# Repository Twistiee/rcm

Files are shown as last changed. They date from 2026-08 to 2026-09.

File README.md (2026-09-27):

# RCM — Relay Control Module

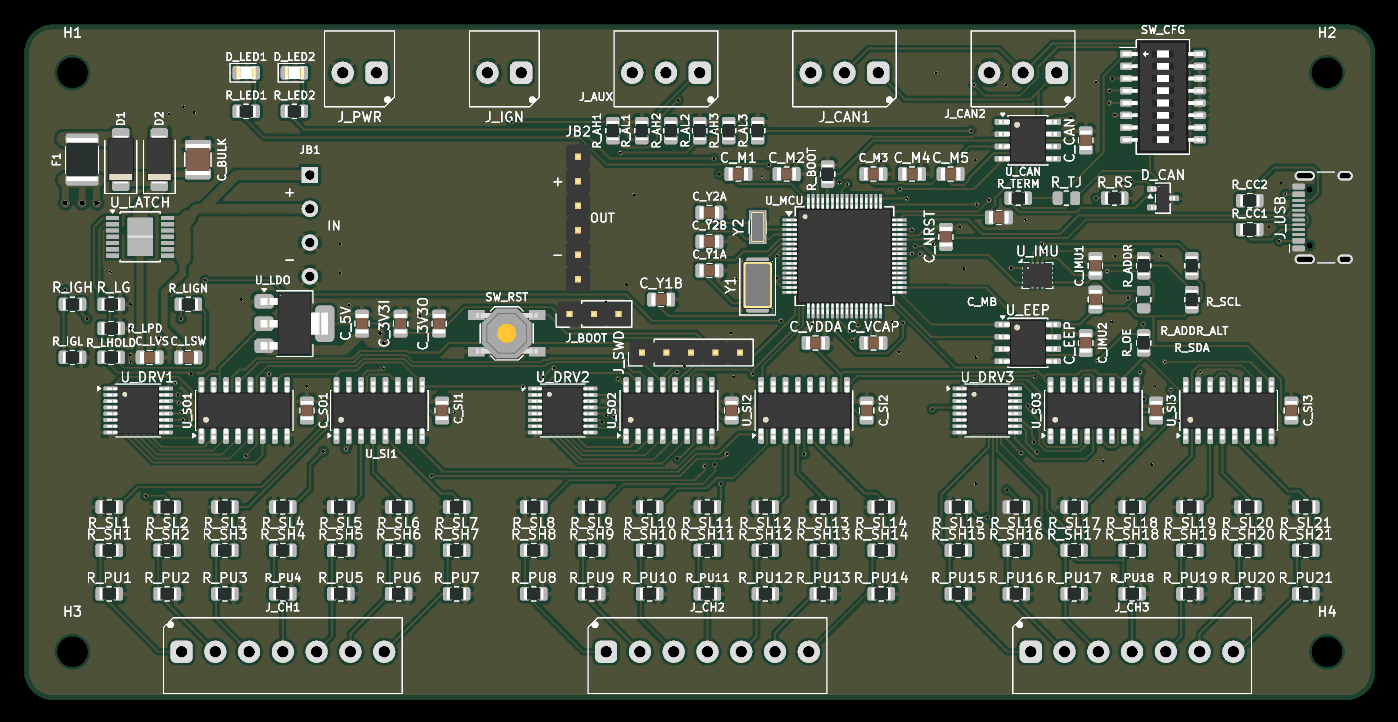
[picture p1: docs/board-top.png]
RCM board, top view


A CAN-controlled relay driver for a car. **21 universal channels**, each of which is
simultaneously a low-side output *and* an input — so the same board builds as a relay
controller or as a switch panel, decided in firmware rather than by a different PCB.

Designed for a [rusEFI](https://rusefi.com/) bus (uaEFI SUPER ECU + uaDASH display), but
nothing about it is rusEFI-specific beyond the choice of message IDs.

> ### A note on how this was built
>
> **This project is largely AI-developed.** The schematic, PCB layout, firmware and
> documentation were written by me working with Claude, and much of the text and code here
> came out of that. It is called out up front because some people would rather know, and
> because it should colour how much you trust it.
>
> What it does *not* mean is unreviewed or untested. The board exists and has been brought
> up on the bench; the claims in the Status section below were measured rather than
> asserted, and where something has only been reasoned about it says so. The firmware has a
> host-side unit test suite. Bring-up still found real bugs that review had missed — which
> is rather the point of the Status section.
>
> Treat it as you would any one-person hobby project: read the schematic before you build
> it, and don't put it in charge of anything you can't afford to have fail.

---

## Status — read this first

**revA has been built, powered and brought up.** Every subsystem has run on real
hardware: the MCU and its 8 MHz crystal, USB, the DIP straps, the EEPROM, CAN through the
transceiver onto a real bus, the IMU, the 12 V sense, the self-latching power, the
watchdog, the output drivers under a real relay load, a stored configuration surviving a
full save-reset-read cycle, and the board switching itself off. 268 host unit tests pass
alongside that.

What that does **not** mean is that it is proven in a car. Specifically, still untested:

- **board-to-board peer mirroring** — the keypad role strap is proven and a board does
  come up as a keypad, but only one board has ever been powered, so the peer link has been
  exercised only with a PC pretending to be the other board
- **more than two channels under load at once**, and nothing thermal

One genuine hardware flaw has been found, and it is a missing capability rather than a
functional fault: **revA cannot reach USB DFU.** `BOOT1` is `PB2`, which this board uses
for `SR_OE_N` and holds high at reset, so lifting BOOT0 boots from SRAM instead of the ROM
bootloader. The `J_BOOT` header is fitted and works; the pin conflict defeats it. Firmware
therefore needs an ST-Link on `J_SWD`. Configuration is unaffected — that is all over CAN.
`DESIGN.md` has the analysis and the one-net revB fix.

Bring-up found three real firmware bugs that no amount of desk testing had: a `%f` in
printf corrupting memory, a strap display that could never show a change, and a short
press on the ignition button switching the board back off. `DESIGN.md` records those and
everything else found along the way, which is a fair guide to how much is probably left.

### What happens when it resets

This is a PDM. Running a main relay, a fuel pump and an injector feed is the job, not an
edge case. But there is one behaviour to design around:

**On any reset, `R_OE` parks all 21 channels high-impedance until firmware re-enables
them.** Every channel drops. The firmware adopts `failsafe_state` and goes live as its
first act, and on revA hardware that is **22 ms**, measured by the self-test build's `W`
command rather than estimated. Add a few ms of pre-`main()` crystal and PLL startup that
`millis()` cannot see, so call it **~25 ms**. That applies equally to a cold start and to
a watchdog reset, so a main relay behind this board closes with the key rather than after
a timeout.

Most of the 22 ms is the EEPROM: the board cannot apply `failsafe_state` before it has
read `failsafe_state`, so `cfg_load()` is unavoidably inside the dropout. A scope on any
channel gives the true figure including pre-`main()` time.

So the question for each load is not "is this engine-critical" but **"what does 25 ms off
do to it?"**

| Load | 25 ms off | Verdict |
|---|---|---|
| Fan, fuel pump, lights, horn, accessories | invisible | fine |
| Injector / coil supply via a main relay | at worst a single missed event | **fine — set `failsafe_state` to hold it on** |
| **ECU power itself** | the ECU reboots, which really is a stall | **give the ECU its own ignition-switched feed** |
| **Brake lights** | harmless in itself | **hardwire anyway** — see below |

**`failsafe_state` is the board's resting state**, not just a bus-timeout behaviour: it is
what gets applied at power-up, after a watchdog reset, and whenever the bus goes quiet —
anything a CAN command has not overridden. It defaults to all-off, which is right for
lighting and wrong for anything that should be on by default. It is per-channel, so one
board can drop its lighting and hold its engine loads. Set it deliberately.

**Brake lights are a different argument.** Not dropout time — a hardwired brake switch is
simply simpler and more reliable than anything running on a microcontroller, and there is
no upside to inserting one. Wire the switch straight through, and tap the switched feed
into a spare channel set to `CH_INPUT` if you want the board to know about it. 1.2 mA, and
it cannot affect the lamps.

Roadworthiness and legal compliance of anything you build with this are yours.

---

## What it does

| | |
|---|---|
| **Channels** | 21, low-side switched, 7 per driver |
| **Drivers** | 3 × TPL7407L (MOSFET, not Darlington — see below) |
| **I/O expansion** | 74HC595 out / 74HC165 in, daisy-chained |
| **MCU** | STM32F446RET6, LQFP-64 |
| **Bus** | CAN, switchable termination, any exact bitrate |
| **Sensing** | every channel is read back continuously, including while driving |
| **IMU** | Bosch BMI270, 6-axis |
| **Board** | 140 × 70 mm, 4-layer, solid ground plane |

## Ratings

| | |
|---|---|
| Supply | 7–30 V (12 V nominal); board draws ~100 mA |
| **Per channel, one or two on** | **600 mA** sink, 30 V max |
| **Per channel, all 7 of a tile on** | **~250 mA** — limited by the driver package, not the silicon |
| All 21 channels | ~3.5 A total with typical 85 Ω relay coils |
| Ground return | **all channels share one pole on `J_PWR`**, ~8 A |
| Ambient | −20 to +70 °C |

The channels **switch relay coils, they do not carry load current** — that is the whole
architecture. `DESIGN.md` has the worked numbers, including why 600 mA is not an all-on
figure.

## The channel trick

Each channel's terminal connects to three things at once — a driver output, a permanently
connected 1M/270k sense divider, and a fitted 10k pull-down:

- **As an output** it sinks a relay coil to ground.
- **As an input** a button wired to +12V pulls it high; the pull-down gives 1.2mA of wetting
  current, enough to keep switch contacts from going oxide-flaky.
- **As a diagnostic**, because the divider never disconnects, an idle channel reads battery
  voltage through a healthy relay coil and 0V through a blown fuse. **Fuse detection falls
  out of the same wiring** — no extra parts.

Getting all three from one resistor took a few goes. A pull-*up* would have been the obvious
choice and it silently breaks fuse sensing: blown and healthy both read high, 20mV apart.

The same pull-down has a sting worth knowing: an un-driven channel is **not open**, it is
10k to ground, and it will pass ~1mA from anything pulled up to 12V. Relay coils ignore
that. Optocouplers and MOSFET gates do not — so a generic "active low" relay module wired
straight to a channel sits with its relays energised. `DESIGN.md` has the fix.

## Configuration

An 8-way DIP sets what can't be fixed over the bus once it's wrong:

| Pos | Function |
|---|---|
| 1 | CAN termination (passive, parallels a solder jumper) |
| 2 | Role — relay module or keypad |
| 3–4 | Node address |
| 5 | CAN bitrate — forces 500k, for when you configure yourself off the bus |
| 6 | Publish IMU data — only one board per car should |

Four relay modules and four keypads can share a bus. Everything else — channel modes,
bitrate, message IDs, failsafe states — lives in EEPROM and is changeable over CAN.

## Firmware

PlatformIO + STM32duino, in [`firmware/`](firmware/) — see
[`firmware/README.md`](firmware/README.md) for the detail.

- 21 channels, in or out per channel as a **software** table, changeable over CAN
- **Coil-circuit diagnosis** — blown fuse, missing relay, open coil or broken wire, all
  reported per channel, and a short-to-12V too
- **Input behaviours**: momentary, **toggle** (a momentary button driving a latching
  load), and **hold-to-arm** (true only once held, for things a knock must not arm)
- **Output behaviours**: steady, flash on a shared period so several channels stay in
  phase, single pulse, and delay-off
- CAN at **500 kbps by default and any exact bitrate you like**. Bit timing is solved at
  runtime for an 87.5% sample point; if a rate cannot be produced exactly, it refuses to
  start rather than running the bus 1% out
- Node addressing for 8 boards, CAN-loss failsafe, ignition-off shutdown, watchdog
- **Everything is configurable over CAN, and readable back over CAN** — every setting has
  a getter as well as a setter, so a tool can ask a board what it is rather than infer it
- Optional **keypad → relay peer mirroring**, so a button panel can drive a relay module
  with no ECU in the middle

```
pio run -d firmware                     build
pio run -d firmware -e selftest -t upload   bring-up console over USB-C
pio test -d firmware -e native          268 host unit tests
```

**Two bring-up paths.** A **USB-C console** needs nothing but the cable — it proves the
DIP, the EEPROM, the CAN controller via internal loopback, the IMU, and walks all 21
channels. A **PC-side CAN tool** (`firmware/tools/rcm_bench.py`, any python-can interface)
does monitoring, commanding and the same channel walk over the bus.

The unit tests compile the firmware's own source against a model of the board — the shift
register chains bit by bit, each channel's electrical behaviour, and the EEPROM including
its page-wrap misbehaviour. They exist because the shift-register byte order is the one
thing in this design that cannot be checked by reading the code back.

### rusEFI

Message IDs were checked against rusEFI's own source rather than guessed. The board sits at
base `0x300`, clear of everything rusEFI uses (`0x100`/`0x102`, `0x130`/`0x131`, `0x190`,
`0x200`–`0x20B`, OpenBLT, OBD2). The base is configurable if it clashes with something on
your loom.

[`docs/rcm.dbc`](docs/rcm.dbc) is generated from the firmware headers, so **uaDASH and
TunerStudio can render channel state, inputs and faults with no custom display code**.

**The board can drive channels from the ECU's own decisions, and ask the ECU to act.**
rusEFI broadcasts what it thinks its relays should be doing — main relay, fuel pump, both
fans, O2 heater, check-engine, rev limiter — as single bits. Any of those can be bound to
a channel, so the ECU decides and this board switches, which matters because rusEFI has
far fewer outputs than this board has channels. In the other direction, a button can send
any TunerStudio command: start/stop the engine, or one of rusEFI's Lua command counters,
which is how you get traction control, launch control or a map switch without either side
needing new firmware.

The BMI270 publishes as a **Bosch MM5.10** at `0x174`/`0x178`/`0x17C` — frames rusEFI
already decodes. Set `imuType = IMU_MM5_10` and yaw rate plus lateral, longitudinal and
vertical G appear in the ECU with nothing else to configure.

## Enclosure

[`enclosure/`](enclosure/) generates a sealed 3D-printable box and two lids — a keypad face
carrying eight 25 mm anti-vandal switches, and a blank plate for the relay-control build.
Wire entry is DEUTSCH DT, one aperture that fits 2, 3 and 4-way alike.

Like the PCB, it is generated by a script rather than modelled by hand; the `.FCStd` files
are output and are overwritten on every build.

## Building one

The schematic and PCB are **generated, not drawn**:

```
python gen_spec.py     ->  spec.json        the circuit, and the source of truth
python gen_plan.py     ->  board_plan.json  every part's physical position
tools/                                      schematic, placement, routing, export
```

Editing `rcm.kicad_sch` or `rcm.kicad_pcb` by hand gets overwritten. Change the generator.

`mfg/` holds the gerbers, BOM and CPL exactly as ordered, so you can send that folder to a
board house without running any of the above. It is set up for JLCPCB assembly: 4-layer,
leaded HASL, Standard PCBA (the BMI270's LGA-14 package requires it).

## Parts you must supply yourself

The board house builds the board. **These are not on the BOM and will not arrive with it** —
either because they do not mount to the PCB, or because no standard part fits.

### The buck module (required — the board does not power up without it)

A **Waveshare DC5-36-TO-DC3V3-5** step-down module, socketed onto `JB1`/`JB2`. It takes the
ignition-latched 12V rail down to 5V, which the on-board LDO then drops to 3V3.

**It ships set to 5V output and must stay that way.** Getting 3V3 from the module instead
needs per-unit pad rework, and forgetting it once puts 5V into a 3.3V MCU. The LDO exists
precisely so that step is never required.

Two things go with it:

| | |
|---|---|
| `JB2` (output, row of 6) | ordinary 2.54mm male header, **on the BOM** (`C37208`) |
| `JB1` (input, 4 pins) | **hand-fit** — 3.50mm pitch, no header is made at that spacing |

`JB1` needs four individual square pins. They set the module's ride height, so fit them
before anything else and get it square.

### Mating plugs for every terminal (required to connect anything)

The board carries the header halves; the screw plugs are yours to buy. `KF2EDGK-3.5-xP`,
also sold as `15EDGK-3.5`:

| Plug | LCSC | Mates with | Per board |
|---|---|---|---|
| 2P | `C440847` | `J_PWR`, `J_IGN` | 2 |
| 3P | `C440848` | `J_AUX`, `J_CAN1`, `J_CAN2` | 3 |
| 7P | `C440852` | `J_CH1`, `J_CH2`, `J_CH3` | 3 |

About $3.20 a board. Generic parts — any supplier stocks them.

> **Do not buy these into JLC's Parts Library expecting them to ship with the boards.**
> Confirmed the hard way on the 2026-08-08 order. That library is consignment stock for
> assembly runs, and JLC will only ship a part if the assembly process solders it down —
> a loose mating plug does not qualify. They will not add it to the board, and they will
> not put it in the box for a sane handling fee either. Money spent there is stuck: you
> own the parts and there is no way to take delivery of them.
>
> Buy the plugs somewhere else entirely.

### Optional

| | |
|---|---|
| `R_TJ` | 0R 0805 (`C17477`) — solder for permanent CAN termination instead of the DIP |
| Momentary buttons | for a keypad build: 8 off, positive-switched to +12V |
| USB-CAN adapter | for the PC-side tool. Get one with **slcan** firmware |

## Repository layout

```
gen_spec.py      -> spec.json         circuit definition, the source of truth
gen_plan.py      -> board_plan.json   every part's physical position
jlc_parts.json                        LCSC part per line; stamped into the schematic
tools/                                scripted-board pipeline
mfg/                                  gerbers, BOM, CPL as ordered
firmware/                             STM32 firmware, host unit tests, PC tools
enclosure/                            generated 3D-printable box and lids
docs/rcm.dbc                          CAN database, generated from the firmware headers
SPEC.md / DESIGN.md                   what was built, and why
```

## Honest notes

`DESIGN.md` is a decision log rather than a specification, and it keeps the mistakes in.
Some that seem worth repeating here:

**Three faults were caught after the board looked finished and every automated check was
green** — a missing ground pour, a reverse-polarity diode wired backwards, and stale
manufacturing files. Two were spotted by eye, not by tooling. ERC passes a diode in either
orientation, and DRC says nothing at all about an absent copper pour.

**The unit tests earned their keep before any hardware existed.** They caught a mirrored
shift-register byte order, a CAN filter that made every other filter decorative, four
broadcast frames being handed to three transmit mailboxes, and a multi-second output
dropout after a watchdog reset. The pattern in every case was two independent derivations
of the same fact disagreeing — which is why the tests model the hardware rather than
restating the driver.

**`JB1`** (the buck's input pins, 4 holes at 3.50mm pitch) is hand-fit — no header is made
at that pitch. Respacing it to 2.54mm is the obvious fix for a revision.

## Credits

`firmware/lib/bmi270/` is Bosch Sensortec's own
[BMI270 Sensor API](https://github.com/boschsensortec/BMI270_SensorAPI), vendored verbatim
under BSD-3-Clause. It carries the 8 KB configuration image the sensor needs at every
power-up, which is not something worth reimplementing.

## Licence

[MIT](LICENSE) — hardware design files included. Copy it, change it, sell it, no
attribution burden beyond keeping the notice.

MIT rather than a public-domain dedication for one reason: the **"AS IS, WITHOUT WARRANTY"**
clause. This switches vehicle electrics, and that paragraph is worth keeping.

Bosch's vendored BMI270 driver is separately licensed under BSD-3-Clause.

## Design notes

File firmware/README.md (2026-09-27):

# RCM firmware

STM32F446RET6, PlatformIO + STM32duino. Drives 21 universal channels behind shift
registers, talks CAN to a rusEFI bus, and diagnoses its own relay circuits.

**Status:** feature-complete for bench bring-up, **never run on hardware** — the boards
were ordered 2026-08-08 and have not arrived. Everything below is written, compiling, and
unit-tested against a model of the board. None of it has seen a relay.

```
pio run                          build for the board
pio run -t upload                flash over J_SWD with an ST-Link
pio run -e selftest -t upload    bring-up console on the USB-C port
pio test -e native               268 host unit tests
python tools/gen_dbc.py          regenerate ../docs/rcm.dbc
python tools/test_rcm_bench.py   self-test the bench tool, no hardware needed
python tools/rcm_bench.py --help talk to a board over CAN
```

---

## What is here

| | |
|---|---|
| `include/board.h` | pin map, taken from `gen_spec.py`'s `PINMAP` — do not hand-edit |
| `src/shiftreg.cpp` | 3× 74HC595 out + 3× 74HC165 in, one shared SPI1 transfer |
| `src/channels.cpp` | channel modes, debounce, coil-circuit diagnosis |
| `src/canbus.cpp` | bxCAN on the HAL, bit timing solved for any bitrate |
| `src/protocol.cpp` | frame layouts, commands, failsafe, peer mirroring |
| `src/store.cpp` | M95640 EEPROM driver |
| `src/config.cpp` | straps from the DIP, configuration from EEPROM |
| `src/imu.cpp` | BMI270 → Bosch MM5.10 CAN frames |
| `src/main.cpp` | boot order, scheduler, ignition shutdown, watchdog |
| `src/selftest_main.cpp` | bring-up console over USB CDC, its own build environment |
| `lib/bmi270/` | Bosch's own BMI270 driver, vendored (BSD-3) |
| `test/` | host unit tests + a model of the board |
| `tools/rcm_bench.py` | PC-side CAN tool: monitor, command, channel walk |
| `tools/gen_dbc.py` | generates `docs/rcm.dbc` from `protocol.h` |

---

## Boot order is a safety property

Three things happen in this order and the order is not negotiable:

1. **`LATCH_HOLD` high**, as the first statement in `setup()`. Until it is, the board is
   alive only while the ignition signal is, and it cuts out mid-boot the moment you
   switch off. Nothing is debuggable before this works.
2. **A zeroed frame shifted out and latched**, with `SR_OE_N` still high. `R_OE` holds the
   595s in high-impedance from the instant power arrives; that is what stops 21 relays
   clacking on during boot. Until a known state is latched, dropping `SR_OE_N` would put
   power-on garbage onto the coils.
3. **Only then** may the outputs go live.

`test_shiftreg` asserts all three.

---

## Channel modes are software, and only software

Every channel has the same three resistors fitted, and every channel is simultaneously an
output and an input in hardware — the sense divider never disconnects. What a channel *is*
comes from `cfg.ch[n].mode`:

| Mode | Behaviour |
|---|---|
| `CH_OUTPUT` | drives a relay coil low-side; sense reports coil-circuit health |
| `CH_INPUT` | never driven; sense is a button switching +12V |
| `CH_UNUSED` | never driven, never diagnosed |

Commands to a channel that is not `CH_OUTPUT` are **ignored**. That is a safety property,
not tidiness: driving a channel wired to a button would short that button's +12V feed to
ground through the TPL7407L.

### What a sense bit means

| | Reads |
|---|---|
| Output, driver off, coil circuit intact | HIGH |
| Output, driver off, fuse blown / open circuit | LOW |
| Output, driver on | LOW |
| Input, button open | LOW |
| Input, button closed to +12V | HIGH |

So **an output can only be diagnosed while it is off.** That is not worth engineering
around — a relay that is commanded on and drawing current announces a broken circuit the
moment it is next switched off.

Two timers keep it honest. `output_settle_ms` (100ms) ignores a channel's sense after any
commanded change, because a coil's flyback takes real time to collapse and diagnosing
inside that window makes every switch-off look like a blown fuse. `fault_confirm_ms`
(500ms) then requires the condition to hold — a car is a terrible electrical environment
and one bad sample is noise.

---

## CAN

### Where the IDs came from

Checked against rusEFI's own source rather than guessed. What rusEFI occupies:

| | |
|---|---|
| `0x100`, `0x102` | TunerStudio over CAN |
| `0x130`, `0x131` | VAG yaw/lateral-G IMU input |
| `0x150`, `0x151` | Mercedes A0065422618 IMU input |
| `0x174`, `0x178`, `0x17C` | Bosch MM5.10 IMU input |
| `0x190` | rusEFI wideband O2 |
| `0x200`–`0x20B` | rusEFI verbose gauge broadcast |
| `0x667`, `0x7E1` | OpenBLT bootloader |
| `0x7DF`, `0x7E0`–`0x7E8` | OBD2 |
| `0x770000`+ | bench-test protocol (extended IDs — no clash with 11-bit) |

**`0x300` is clear of all of it**, so that is the default base. It is not baked in:
`can_base_id` lives in EEPROM and can be moved over the bus.

```
base + node*0x10 + f    f = 0..15, one 16-ID block per node
base + 0x80             global control, every node listens
```

Eight nodes (4 DIP addresses × 2 roles) fit in `0x300`–`0x380`.

### Frames

| Offset | Name | Direction |
|---|---|---|
| `+0` | `OUTPUTS` — commanded states, status flags, uptime, node id, seq | TX |
| `+1` | `INPUTS` — debounced inputs, aux, **raw sense for every channel** | TX |
| `+2` | `FAULTS` — open-circuit bits, short-to-12V bits | TX |
| `+3` | `STATUS` — firmware version, bus-off, ignition mV, CAN error counters | TX |
| `+8` | `CMD_SET` — 21-bit mask + 21-bit values | RX |
| `+9` | `CMD_CTL` — opcode + up to 4 argument bytes | RX |

`INPUTS` carries the raw sense bits alongside the logical ones deliberately. It costs
nothing and it is the most useful thing on the bus when something is miswired — you can
see what a pin is actually doing without having to agree with the firmware about what
that pin is *for*.

### uaDASH: use the DBC, don't imitate rusEFI

uaDASH renders any third-party broadcast it has a DBC for. So rather than squeezing 21
channels into a frame layout designed for RPM and coolant temp, the board broadcasts its
own clean frames and ships **`docs/rcm.dbc`** alongside — 52 messages, 1409 signals,
generated by `tools/gen_dbc.py` and validated with `cantools`.

**Keep them in step.** The generator reads the IDs straight out of `protocol.h` so those
cannot drift, but signal *layouts* are written in both places.

### The IMU is the exception, and the happy one

rusEFI already decodes Bosch MM5.10 accelerometer frames natively. Our IMU is a Bosch
BMI270. So the board emits MM5.10 at `0x174`/`0x178`/`0x17C`, and the ECU picks up yaw
rate and lateral/longitudinal/vertical G with **nothing to configure but
`imuType = IMU_MM5_10`** in TunerStudio.

Two honest caveats:

- We emit only the fields rusEFI reads (bytes 0–1 and 4–5). A real MM5.10 also puts a
  status nibble, a rolling counter and a CRC in the gaps. Anything that validates those
  will reject these frames.
- The MM5.10 encoding saturates at ±163.8 °/s of yaw. That is most of the way through a
  spin, and the encoders clamp rather than wrap — a wrapped yaw rate would tell the ECU
  the car had suddenly turned the other way.

### Which way up the board is mounted, and which way it faces

The IMU can be bolted in at **any angle at all**. The orientation is stored as two
measured unit vectors -- where UP is and where FORWARD is -- orthonormalised into a
rotation matrix, not as an axis permutation.

That distinction is the whole point. A permutation can only snap to 90 degrees, and a
real bracket is never square. The error is silent and permanent:

| Lean | Gravity leaked into the horizontal axes |
|---|---|
| 5 deg | 0.087 g |
| 10 deg | 0.174 g |
| 15 deg | 0.259 g |

Moderate braking is about 0.3 g, so even a 5 degree mount biases longitudinal G by a
third of a real event, always, with nothing to indicate it. Measured on a real board
sitting on a slightly tilted bench: **lateral read -0.217 g while completely still**.
After levelling, the same board read -0.001 g. It was 12 degrees off square -- inside the
old 15 degree tolerance, so the previous axis-map version would have *accepted* that
reading and ignored the error rather than refusing it.

#### Calibrating from three switches, with no laptop

Give the J_AUX pins jobs. Each is **held for 2 seconds**, never tapped, and J_AUX inputs
are active-high like the channels -- feed 12 V through a momentary.

| Label | Hold it to |
|---|---|
| `imufwd` | Set **FORWARD**. Hold the board with the edge you want at the REAR of the car pointing at the ground |
| `imulevel` | Set **UP**, in the final mounted position. Keeps the forward direction |
| `cfgsave` | Commit to EEPROM. Calibration is never auto-saved |

```
rcm_bench.py ctl auxfunc 1 imufwd
rcm_bench.py ctl auxfunc 2 imulevel
rcm_bench.py ctl auxfunc 3 cfgsave
rcm_bench.py get imu          # nearest square mounting + how far off square it is
```

Together those cover **all 24 orthogonal mountings and everything in between**: levelling
picks which way is up, aiming picks which of the four remaining rotations is forward.
Gravity alone can never do the second -- rotate a board on a level bench and gravity does
not change -- which is why aiming is a separate step rather than something levelling
guesses at.

**Why forward is measured by pointing the rear edge down:** an accelerometer at rest
reads +1 g along whichever axis points up. Hold the rear edge at the ground and the axis
pointing up is the one that will face forward. It is the same measurement levelling
makes, read differently.

**The LEDs answer**, because two of the outcomes are refusals and a refusal otherwise
looks identical to a press the board never saw:

| While held | green/red alternate at 2 Hz -- seen, keep holding. Release early to abort |
|---|---|
| **green x4** | done |
| **red x2** | moving -- the board must be still, and *turning* counts even though gravity still totals 1 g |
| **red x3** | the two directions are within 20 degrees of parallel; you held it flat during the FORWARD step |
| **red x4** | no IMU, or the `CFG_IMU_EN` strap is open |
| **both together x2** | config saved |
| **red x5** | the save FAILED |

Deliberate awkwardnesses, each with a test: held not tapped, since re-levelling rewrites
how the board reports the car's motion; once per press, so a stuck switch levels once
rather than forever; and **a switch already closed at boot is a baseline, not a press** --
otherwise a shorted pin re-calibrates two seconds into every power-up.

#### Setting it by hand instead

```
rcm_bench.py ctl imumap x y z       # board flat, +X edge pointing down the car
rcm_bench.py ctl imumap ny x z      # the same board rotated 90 deg clockwise
```

Write a negated axis as `ny`, not `-y` -- a leading dash is taken for a command-line
option. A square mounting set this way lands on exactly +/-1, so nothing is lost.

**A left-handed map is refused, not corrected.** X and Z determine Y completely; if the Y
you asked for is not the one that falls out, the frame is mirrored and the command is
rejected. A mirrored frame reads perfectly plausibly standing still and only shows up as
the car yawing the wrong way through a corner. (The earlier validator checked only that
the three axes were distinct, and let this through.)

Mount it **rigidly** either way -- on a compliant bracket you measure the bracket
resonating, not the car.

### IMU publish rate, and what actually limits it

`imu_rate_ms` sets the publish period; the sensor ODR follows it automatically, at least
2x where the part allows. Publishing faster than the ODR is the trap worth naming --
the same sample goes out repeatedly and looks exactly like real data arriving faster.

```
rcm_bench.py ctl imurate 5      # 200 Hz
rcm_bench.py get timing2        # reads it back
```

Measured on real hardware over the bus, not calculated:

| Setting | Nominal | Measured | Bus load |
|---|---|---|---|
| 20 ms | 50 Hz | 50.5 Hz | 6.1% |
| **10 ms** | **100 Hz** | **101.3 Hz** | **10.1%** |
| 5 ms | 200 Hz | 202.6 Hz | 18.0% |
| 4 ms | 250 Hz | 246.4 Hz | 21.4% |
| 3 ms | 333 Hz | 249.5 Hz | 21.7% |
| 2 ms | 500 Hz | 253.1 Hz | 22.0% |

**The board tops out at about 250 Hz**, and asking for more just gets you 250. The limit
is the main loop, which iterates in roughly 4 ms -- the blocking I2C read of the BMI270,
plus the shift-register I/O and the CAN work -- not the sensor (which reaches 800 Hz) and
not the bus.

**But the default is 100 Hz, and the reason is at the far end, not this one.**

rusEFI consumes MM5.10 **event-driven** -- `CanRead` blocks on receive and every frame
goes straight to `processCanRxImu()`. There is no sampling rate, no decimation and no
staleness check. So nothing we send is discarded, and sending faster genuinely does
deliver fresher data.

The catch is that all three handlers call `efiPrintf` **unconditionally**, not gated
behind `verboseCan`. At 200 Hz that is 600 console prints per second on the ECU, forever,
purely because this board is on the bus. That cost scales linearly with our rate and
lands on the *ECU* rather than the bus, which is a worse place for it than an arbitration
delay -- and it will bury the rusEFI console.

100 Hz is also the rate this sensor family is usually quoted at, so it is what rusEFI was
written against.

Two things worth knowing about that consumer, neither of which we control:

- **No staleness detection.** If this board drops off the bus, the last G values sit in
  `engine->sensors.accelerometer` indefinitely and nothing flags it. The wideband path
  uses `CanSensorBase`, which does have timeouts; the IMU path predates it and carries a
  `// TODO: convert to CanListener`. Our own ECU-follow inputs *do* have a staleness
  timeout, so the asymmetry is worth remembering: we distrust the ECU going quiet, and
  the ECU does not distrust us.
- **A 50 Hz figure in rusEFI is the SPI accelerometer**, not this path -- that is
  `useSpiImu = true`, a 20 ms periodic thread. Do not take it as the CAN rate.

Raising the ceiling here would mean a non-blocking or DMA I2C read. Not worth it unless a
strategy is ever shown to need fresher than 10 ms.

### Bitrate

Solved for at runtime from the actual APB1 clock, targeting an 87.5% sample point, and
**exact rates only** — if no `(BRP, TS1, TS2)` divides out exactly, `can_begin()` fails
rather than settling for close. A 1% bitrate error works on the bench and fails in the
rain; a hard failure at boot is a much better outcome. (Note this rules out 800k on a
45MHz APB1, which is asserted at compile time.)

`CFG_BAUD` closed forces 500k regardless of what is stored. That is a *recovery*
mechanism, not a selector: you cannot fix a bad CAN setting over CAN, so one switch has to
beat any configuration.

### Peer mirroring

The shortest path from a keypad to a relay module without an ECU in the middle. Set
`peer_node` and a relay module applies that node's debounced input bits straight to its
own outputs, channel for channel. `peer_mask` bounds what it may touch;
`peer_toggle_mask` picks channels where a *press* toggles rather than follows.

Prefer setting the **input behaviour** to `IN_TOGGLE` on the keypad instead, where
available: the latched state then travels in the keypad's own INPUTS frame, so mirroring
just follows it, a dash sees the real state, and any ECU command bound to that button gets
one edge per intent. `peer_toggle_mask` un-picks it at the destination, which only ever
works for the one consumer that implements it.

The first frame from a peer only establishes a baseline, so a board joining the bus while
a button happens to be held does not fire every toggle channel at once.

---

## Configuration

**Straps** come from the DIP and can only change with the power off — role, node address,
IMU enable, and the 500k override. These are exactly the settings you cannot fix over the
bus once they are wrong, which is why they are on a switch.

**Everything else lives in EEPROM and is settable over CAN** — bitrate, base ID, timings,
channel modes and behaviours, failsafe states, peer mirroring, IMU axis remap, the ECU
command and follow tables.

**And readable back over CAN.** `RCM_OP_GET_CFG` takes a selector and an index and answers
on its own frame. That is not a convenience: without it every check has to be behavioural,
which is how a bench session ends up concluding something from a stale broadcast frame.
`rcm_bench get` dumps the lot.

### A channel's role is its label, and nothing else

The ignition machinery needs to find four channels: the start pedal, the starter, the
engine-running signal, and the RUN output that feeds an ECU's ignition input. Those are
named by the channel's **function label** and nowhere else.

There used to be a second copy — `ign_brake_ch` and friends — with nothing tying the two
together. Label channel 12 "Brake pedal", point `ign_brake_ch` at channel 5, and the board
reads the brake from 5 while every display says 12. Pressing start with a foot on the
brake then does nothing, the configuration looks correct, and you go and suspect the
switch. One record of a role, so nothing can disagree with it.

### The start button's lamp

Label the channel feeding the start button's LED `FN_IGN_LAMP` and the ignition state
drives it:

| Lamp | Meaning |
|---|---|
| slow blink (1 s on, 1 s off) | ignition on, engine not running |
| fast blink (4 Hz) | starting |
| **solid** | **running** -- lit so the button can be *found in the dark* to stop the car |
| off | shutting down |

```
rcm_bench.py ctl chmode <ch> out 2      # 2 = CH_F_NO_DIAG, see below
rcm_bench.py ctl chfunc <ch> ignlamp steady
```

**Set `CH_F_NO_DIAG`.** An LED cannot pull the channel node up to +12 V through the 10 kΩ
pull-down the way a relay coil does, so the fuse-sense diagnosis reads it as a permanent
open circuit and lights the red fault LED. There is nothing to diagnose on an LED.

**"Starting" covers two different things.** If this board owns the starter it is simply
`IGN_ST_CRANKING`. On a one-button car the **ECU** owns the starter and this board never
cranks anything -- it sends start/stop and waits. So a start request in flight also counts,
until the engine is seen running or `ign_crank_max_ms` passes. Without that, on exactly the
installation this was written for, the lamp would never show a start.

**"Running" is only as good as the run source.** With none configured, or a CAN RPM source
on a quiet bus, the lamp honestly stays on the slow blink rather than claiming the engine
is running.

Note the start button's *switch* does not use a channel at all: it goes to `J_IGN`, because
it has to wake the board through the hardware latch. Only its lamp takes a channel.

### Which pedal starts the car

**The clutch if a channel is labelled `FN_IN_CLUTCH`, the brake otherwise.** There is no
setting for this — the label *is* the setting, for exactly the reason above.

A manual starts on the clutch: that is the interlock that proves the engine is not about
to drive the wheels, and it is what stops a car being cranked in gear. An automatic has no
clutch and starts on the brake. So labelling the pedal you actually wired chooses the
behaviour, and when **both** are labelled — the normal case, since the brake is wanted
anyway for brake lights and the ECU — the clutch wins and the brake takes no part in
ignition at all.

The pedal does not merely gate cranking, it decides what a press *means*: pedal down is
always an attempt to start, pedal up is always "switch the car off". So swapping pedals
swaps both halves together, which is why they are one lookup rather than two settings.

`GET_CFG`'s ignition selector reports the pedal that **actually gates**, not the brake —
a read-back naming a channel with no say in starting would be a confident wrong answer.
`rcm_bench get ignition` prints it as `start pedal`.

Everything the brake-only version documented about cranking still applies unchanged: the
pedal gates the *start*, not the continuation, because a starter drags the rail to 9–10 V
and a 10.87 V digital input cannot be read through that. Aborting on "pedal released"
would abort every start the instant the starter loaded the battery.

### Storage

Two CRC'd copies at `0x0000` and `0x0400`. The backup is written **first**, so a power
loss between the two writes always leaves one valid record. On boot, a bad primary with a
good backup is repaired immediately rather than rediscovered next time. A blank or
doubly-corrupt EEPROM gives defaults, and the defaults follow the role strap — a fresh
board already does the obviously right thing for what it is.

`RCM_OP_LOAD_DEFAULTS` only touches RAM. Someone has to send `SAVE_CONFIG` as a second,
deliberate act.

---

## Talking to a rusEFI ECU

Two directions, both optional, both configured by table so neither side needs new firmware
when rusEFI adds something.

**The ECU decides, this board switches.** rusEFI broadcasts the state it wants each relay
in — `MainRelayAct`, `FuelPumpAct`, `Fan`, `Fan2`, `EGOHeatAct`, `CELAct`, `RevLimAct` —
as single bits in one frame, re-asserted every broadcast period rather than sent on
change. Bind a bit to a channel and the channel follows it. rusEFI has far fewer outputs
than this board has channels, so this is how the split usually wants to go.

Two details that matter:

- a followed channel whose frame stops arriving **falls back to its failsafe bit**.
  Holding the last value would leave a fuel pump running on the strength of a frame that
  arrived before the ECU died.
- that staleness timeout is **separate from the bus timeout**, because rusEFI multiplies
  its own broadcast period by **five** while TunerStudio is connected over CAN. Sharing
  one value would drop fans and pumps while tuning, and read as a fault in this board.
  Allow at least 5× the ECU's configured period.

**A button asks the ECU to act.** Any input channel can be bound to a TunerStudio command,
sent as an extended frame. Start/stop the engine lands on the same entry point as rusEFI's
own physical start button, so the ECU keeps its own interlocks and decides whether that
means crank or stop. `LUA_COMMAND_1`..`4` bump counters a rusEFI Lua script can watch,
which is how traction control, launch control or a map switch get done — rusEFI has no
fixed command for any of them.

Commands are stored as a raw (subsystem, index) pair rather than a list of names: every
TunerStudio command is that shape, so a new one is a config change rather than a release.
The friendly names live in `tools/rcm_bench.py`, where they cost nothing.

---

## Two ways to bring a board up

### `pio run -e selftest -t upload` — needs nothing but the USB-C cable

An interactive console on the USB-C port. This exists because the first hour with a new
board is exactly when you least want a CAN adapter as a second unknown. It can prove, with
no other hardware at all:

- the board holds its own power on, and the DIP reads
- the EEPROM answers and survives a 40-byte write **across a page boundary**
- the CAN controller, its bit timing and its filter banks, via **internal loopback** —
  a lone CAN node normally cannot transmit at all, because nothing is there to ACK it
- the IMU initialises and reports about 1 g of gravity whichever way up the board is
- every channel drives, and what its sense line reads back

`w` walks all 21 channels with a 2 s dwell, which is bring-up step 5 done for you.
`W` deliberately hangs so the watchdog fires, then reports how long the outputs were
down coming back — the number the top-level README quotes for a reset dropout, measured
rather than estimated.

The one thing it cannot prove is that the transceiver reaches another node.

### `tools/rcm_bench.py` — over CAN, needs an adapter

**What an adapter is:** a PC has no CAN port. A USB-CAN adapter is a dongle with USB on
one end and CANH/CANL on the other, letting the PC join the bus as another node.

**Get one with `slcan` firmware.** It enumerates as an ordinary virtual COM port on
Windows — no driver wrangling — and it is what this tool defaults to. A
[CANable 2.0](https://canable.io/) ships that way, and so does the
[WeAct Studio USB2CANFD](https://github.com/WeActStudio/WeActStudio.USB2CANFDV1)
(STM32G0B1, CAN-FD, works with Cangaroo — this is the one in use here, about NZ$17 on
AliExpress).

The `candleLight`/`gs_usb` firmware is also fine and slightly faster, but on Windows it
needs `pip install "python-can[gs-usb]"` and a WinUSB driver swapped in with Zadig, and
then the tool wants `-i gs_usb -c 0` — a device index rather than a port name.

**Avoid the generic blue/black "USB-CAN Analyzer" dongles** (Waveshare USB-CAN-A and the
many AliExpress lookalikes). They use a vendor-specific serial protocol, not slcan;
python-can only reaches some of them through its `seeedstudio` interface and it is a
fight. Buying on price here costs an evening.

**Wiring and termination.** CANH and CANL to `J_CAN1` or `J_CAN2`, and tie the grounds
together. A CAN bus wants exactly **two** 120Ω terminators, one at each physical end:

- *bench, adapter plus board only* — enable both. `SW_CFG` position 1 on the board, and
  the adapter's own termination jumper.
- *on the car's bus* — the ECU and dash are already terminated. Turn both of yours off,
  or you will load the bus down to four terminators and errors will start appearing.

```
rcm_bench.py -i slcan -c COM5 scan          find nodes
rcm_bench.py -i slcan -c COM5 monitor       live state, sense and faults
rcm_bench.py -i slcan -c COM5 set 3 on
rcm_bench.py -i slcan -c COM5 walk          bit-order check
rcm_bench.py -i slcan -c COM5 faults
```

Any python-can interface works (slcan, socketcan, pcan, kvaser). Decoding goes through
`docs/rcm.dbc`, so the tool and the dash see identical fields.

`--with-sim` runs a fake board in a background thread, which is how the tool was
developed and tested with no hardware. `tools/test_rcm_bench.py` drives that end to end
and also cross-checks the tool's byte packing against the DBC — so bench tool, DBC and
`protocol.h` are pinned to each other.

---

## Testing

268 host unit tests, run with `pio test -e native`. They compile the firmware's **own**
`.cpp` files against a model of the board in `test/stubs/`, so they test the code that
ships rather than a transcription of it.

`test/stubs/simboard.cpp` models:

- the 595/165 chains bit by bit, in both directions
- each channel's electrical behaviour, so a "blown fuse" means the coil cannot pull the
  node up rather than a mock asserting the answer
- the M95640 **including its page-wrap misbehaviour** — a write burst that runs off the
  end of a 32-byte page comes back round and overwrites what it just wrote

That last one matters: `store_write()` splitting at page boundaries is the only thing
between the config record and quiet corruption, and a model that did not reproduce the
misbehaviour would prove nothing.

`canbus.cpp` gets the same treatment through a small bxCAN shim in
`test/stubs/stm32_hal_shim.*` — three transmit mailboxes with controllable availability,
a receive FIFO, and filter banks indexed the way the hardware indexes them.

### What the tests have caught so far

- **The 165 chain mapping.** The two chains run in opposite directions, and the first
  draft of the *model* copied the 595 formula. The driver and the model disagreed
  immediately. That is the whole point — two independent derivations from the netlist only
  agree if both are right, and this is a bug you cannot see by reading either side alone.
- **A surviving accept-all CAN filter.** `can_begin()` parks an accept-all in bank 0 so a
  caller that installs nothing is noisy rather than deaf — but banks are ORed, so it made
  every later filter decorative and left a 3-deep FIFO exposed to the whole bus. The first
  real filter now overwrites bank 0. Found only because the shim indexes banks by number
  rather than appending them.
- **Four broadcast frames into three mailboxes.** STATUS was being dropped every cycle,
  silently and always the same frame. Hence the transmit queue.
- **A reboot latch** in `proto_poll()` that was never cleared. Harmless on real hardware,
  where `NVIC_SystemReset()` does not return, but a reset loop anywhere it did.
- **An auto-level that could not see rotation.** The first version gated only on the
  accelerometer reading ~1 g, which is true of a board being slowly turned over — gravity
  does not change magnitude when you rotate it. Spun flat on a desk it read a perfect
  0.991 g and solved a confident, wrong map. Only found by turning a real board while the
  command ran; every host test had fed it accelerometer vectors alone. It now gates on the
  gyro too, and `test_imu_level` carries the measured numbers from that session.
- **Stale receive frames** in the bench tool — read-back after a command returned frames
  captured *before* it, so every command looked like it had done nothing. True of a real
  slcan adapter as much as of the simulator.

### What is NOT covered

- **`imu.cpp`** — the BMI270 needs an 8KB config upload over I2C to a real chip. Only the
  MM5.10 encoding is checked, via the DBC. The axis solving is split into `imu_level.cpp`
  precisely so it *can* be tested without the chip: `test_imu_level` walks all six square
  mountings, feeds each the gravity vector it would really produce, and checks the map
  that comes back puts Z upright and keeps the axes right-handed.
- **The peripherals themselves.** The HAL shim proves this firmware drives bxCAN the way
  ST document it, not that the silicon then behaves. The self-test build's loopback check
  is what covers that, on hardware.
- **`main.cpp`'s scheduler and shutdown path.**

---

## Bring-up order, when boards arrive

Each step is verifiable with a multimeter before any bus is involved.

### Before you apply power at all

**The board will look completely dead with only `J_PWR` connected.** `+12V_SW` — the
buck's input, and therefore the whole board's supply — is the BTS7040 latch's *output*,
and the latch is held on by `J_IGN`. No ignition signal, no rail, no LEDs, nothing. This
is by design and it is the first thing that will make you think the board is faulty.

**USB cannot power it either.** `USB_VBUS` goes to the connector and stops there; it is
not connected to any rail. USB is for data only.

Three checks with the power off, meter on diode range:

| Check | Expect |
|---|---|
| `J_PWR` pin 1 → pin 2 (12V to GND), both polarities | no short. A few hundred kΩ or open |
| `J_PWR` pin 1 → `C_BULK` +12V pad, red lead on `J_PWR` | ~0.3–0.4 V forward, open reversed |
| 3V3 to GND | no short |

The middle one is worth doing properly: it tests `F1` and `D1` together, and confirms
`D1` is round the right way. That diode was wired backwards in the design once and caught
before the order — `Diode:SS34` has **pin 1 = cathode**, which is not the convention most
people assume. Backwards, it blocks the battery feed and the board never powers up.

### First power-up, staged

Use a bench supply with the **current limit set to about 200 mA**. The board draws
roughly 100 mA. If an assembly short exists, the limit is what stops it becoming a
replacement board.

1. **Buck NOT fitted.** 12 V to `J_PWR`, then 12 V to `J_IGN`. Measure `JB1` pin 1: it
   should sit at about **11.5 V** (12 V less the SS34 drop). Remove `J_IGN` and it should
   collapse. That single test proves the fuse, `D1`, the latch and its divider, with
   nothing downstream at risk.
2. **Fit the buck.** Check it is still set to **5 V out** — it ships that way and must
   stay that way. Confirm 5 V at `C_5V`.
3. **Confirm 3V3** at `C_3V3O`.
4. With a blank MCU the board should stay on only while `J_IGN` is held, because nothing
   is driving `LATCH_HOLD` yet. That is the correct behaviour and a useful signal that
   the latch is doing its job.
5. Only then flash the selftest build.

Nothing connected to any channel terminal for any of this — bare board and buck.

Flash the **selftest** build first — steps 1 to 6 need only the USB cable.

| # | Check | How |
|---|---|---|
| 1 | Board stays alive | LED1 solid (or blinking, see below); board stays on with the ignition input pulled low |
| 2 | Node address | LED2 flashes N+1 times at boot; then `d` in the console |
| 3 | EEPROM | `e` |
| 4 | CAN controller | `c` — internal loopback, no other node needed |
| 5 | IMU | `i` — should read about 1 g total, sitting still; `L` to auto-level |
| 6 | **Bit order** | `w` — walks all 21 channels, meter each terminal as it goes |
| 7 | Fuse detection | wire one relay, pull its fuse, `s` |
| 8 | On the real bus | flash the normal build, then `rcm_bench.py scan` |

Step 6 is worth doing by hand even though the tests cover it. The tests verify the
firmware against **my reading of the netlist**; this verifies the netlist against the
board you are holding. If a terminal lights up that is not the one named, look for an
offset of 14 — that is a mirrored shift-register byte order.

---

## Toolchain notes

- **`-D HAL_CAN_MODULE_ENABLED` is required.** STM32duino leaves bxCAN out of the HAL
  build by default — it is in the "unused modules" list in
  `cores/arduino/stm32/stm32yyxx_hal_conf.h`. Without the flag `stm32f4xx_hal_can.c`
  compiles to nothing and `CAN_HandleTypeDef` does not exist.
- **Clean builds can hit a GCC internal compiler error.** `arm-none-eabi-g++ 12.3.1`
  segfaults intermittently while compiling the STM32duino core under parallel jobs. It is
  not our code and it is not deterministic: re-run the build, or use `pio run -j 1` (26s
  instead of 3s, but it has never failed).
- **Host tests need a host gcc on PATH.** MinGW-w64 (WinLibs) on Windows.
- `HSE_VALUE=8000000U` must match Y1. A wrong value silently breaks CAN timing.

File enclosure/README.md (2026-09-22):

# rcm enclosure

A compact, 3D-printable housing for the rcm board: an open-top tray plus a lid.
Two lids are generated — the **keypad** face carrying eight 25 mm anti-vandal
switches, and a **blank** plate that is the starting point for the
relay-control lid (whose I/O leaves through the lid rather than the box).
The keypad build also gets a small **guard ring** that bonds over the
start/stop button.

Everything is generated by one script. There is nothing hand-modelled, so any
dimension can be changed and the parts rebuilt in about a minute.

```
"C:/Program Files/FreeCAD 1.1/bin/freecadcmd.exe" build_enclosure.py              # both revisions
"C:/Program Files/FreeCAD 1.1/bin/freecadcmd.exe" build_enclosure.py revB-8way    # just one
"C:/Program Files/FreeCAD 1.1/bin/freecadcmd.exe" render_views.py revB-8way       # review images
```

| File | What it is |
|---|---|
| `build_enclosure.py` | the model. `PARAMS` and `VARIANTS` at the top are the only blocks to edit |
| `render_views.py` | shaded views, sections and the bezel print profile into `images/`, no GUI needed |
| `*-revA.FCStd`, `*-revB-8way.FCStd` | **generated — never edit these by hand**, they are overwritten every build |
| `exports/*.3mf` | **for the slicer** — opens straight into PrusaSlicer / OrcaSlicer, in mm |
| `exports/*.step` | for other CAD |
| `images/*-revA.png`, `images/*-revB-8way.png` | review renders, one set per revision |

## Two revisions, and which one you want

Both are built, both are kept, because both are real.

| | revA | **revB-8way** |
|---|---|---|
| Wire entry | 2-way PWR one end, 4-way CAN the other | **one 8-way, one end** |
| For | the relay-module build | **the keypad build** |
| Outside | 162 × 102 × 51.5 | 162 × 102 × 51.5 |
| Box height set by | the switch stack | the switch stack |
| Short-wall screw span | 92 mm | **46 mm** |
| Harness headroom | 30 needed, 32.7 there | 30 needed, 32.7 there |

**revB-8way is the keypad build.** Eight wires arrive on one connector at one
end, which is what the keypad needs and is simply less to make up than two
looms at opposite ends. Two things fall out of that for free:

- the **+X wall is now blank**, so it can finally take a mid-span lid screw.
  That halves the 92 mm screw span, the longest run of unsupported lid;
- the 8-way flange is 35.5 mm tall against the small shell's 31.75, but since
  the lid thinned to 3.5 mm the switch stack is the taller constraint on both
  revisions, so they are now the same height.

Nothing about the lids, the switches or the guard ring differs between them.

## Which way round it goes in the car

The keypad build mounts behind the gearstick, to the driver's left, with the
board **longways** — a short side facing the front of the car. The buttons
therefore run **4 deep front-to-rear and 2 across**.

Which short side faces forward is `car_front`, and it is **−X**, because the
loom comes from the front of the car and enters through the DEUTSCH port,
which is on the `-X` wall.

| | |
|---|---|
| **−X** | front of the car (`car_front`) |
| **+Z** | up |
| **+Y** | the car's **right** — so on a RHD car the **driver's side is +Y** |

Forward and up fix everything else: in a right-handed frame the car's left is
+Y times the front sign, so with the front at −X the car's right is +Y.

**Do not hand-write one of these signs.** Ask `car_axes()`, or say which
button you mean in car terms — `("front", "driver")` — and let
`guard_switch_xy()` map it. Getting front and rear the wrong way round is
what once put the starter on the diagonally opposite corner to the one
intended, and the geometry looked perfectly reasonable the whole time. The
build now prints every port wall in car terms (`-X wall = front`), and
`images/guard_detail-*.png` draws the panel with the car directions labelled
— the quickest way to check you got the corner you meant before printing.

## Sizes

| | mm |
|---|---|
| Outside | **162 × 102 × 51.5** (box 48 + lid 3.5) |
| Cavity | 158 × 98 × 45 deep |
| Wall / floor | **2** / 3 |
| PCB | 140 × 80 as delivered, on 5 mm standoffs, 9 mm clear to the walls |

**The board is 140 × 80, not 140 × 70.** The routed outline in
`rcm.kicad_pcb` really is 140 × 70 — that is what Edge.Cuts says — but the
boards as delivered carry a manufacturing rail on each long edge, because the
components sit close enough to the edge that the panel needs something to hold
on to. Those rails are being **kept on and used as a labelling surface**,
since the silkscreen does not label the terminals, so the box has to house
the 80 mm envelope.

The model keeps the two ideas apart and you should too:

- `pcb_w` / `pcb_d` are the **routed outline**, and `pcb_holes` are measured
  against it in genuine KiCad board coordinates;
- `pcb_tab_w` is the rail, and it only widens the **envelope**.

Set `pcb_tab_w` to 0 if you ever snap them off and the box shrinks by 10 mm
without anything else moving. Had the 80 mm simply been written into `pcb_d`,
the mapping in `board_to_global()` would have shifted every standoff 5 mm and
the board would not have fitted its own mounting holes.

The 9 mm gap around that envelope is not padding: it is what lets a Ø8
lid-screw boss stand in each cavity corner without touching the board, it is
and the channel the harness climbs in. Shrink it and the screws or the wires
have to go somewhere else.

The **wall is 2 mm** and the floor 3 mm. The wall used to be 5 mm, entirely so
its top could carry a seal groove; with the seal gone there is nothing asking
it to be thick, and dropping it took the outside profile in by 6 mm on each
axis and the box from 186 cm³ to 111 cm³.

## Closing it — and why there is no seal any more

**There is no O-ring seal.** `lid_seal` is `False`. The lid lands flat on the
2 mm wall top, located by its lip and pulled down by the screws. Call it
splash-resistant; it is not weatherproof.

It used to be a face seal — a 2.4 × 1.5 mm groove in the lid underside over a
2 mm silicone cord — and that is what the 5 mm wall was for. Taking the wall
to 2 mm killed it outright:

| | |
|---|---|
| Groove width | 2.4 mm |
| Wall it has to sit on | 2.0 mm |
| Land left each side | **−0.20 mm** |
| Lid screw vs groove | **−0.40 mm** (the countersink cut into it) |

The alternatives were a 1 mm cord on a 0.4 mm land, or thickening the wall top
from the inside with a ribbed step. Neither was worth it for this build, so the
groove is gone.

**To put it back** you need a wall that can carry it: set `lid_seal` to `True`
*and* `wall` to at least `seal_groove_w + 2.6` (so 5 mm for the 2 mm cord).
`checks()` will tell you, with numbers, if you have not — the groove geometry
and the cord parameters are all still there, just switched off.

Six or seven M3 screws pull it together, into brass heat-set inserts in the
bosses (Ø4.2 holes; change `boss_hole_d` to 2.6 if you would rather self-tap).
The short walls get no mid-span screw where a DEUTSCH port lives, because a
full-height boss would sit inside the connector body. That leaves 76 mm
between screws on the long walls and 92 mm on the short ones.

**revB halves the short one.** With only one DEUTSCH port, the `+X` wall is
blank and takes a mid-span screw, so that span drops 92 → 46 mm.
`screw_mid_short` accepts a list of walls for exactly this. revA has ports at
both ends and still spans 92; add positions to `screw_extra` and reprint the
lid if the lid lifts, and nothing else has to change.

There is **no USB window** — it is a service port, so take the lid off to
reach it.

## Mounting it to the car

Provisional and deliberately dumb: four Ø4.5 holes straight through the floor
at (±55, ±44.5), for M4. They sit in the 9 mm border strip that runs outside
the PCB, so the heads are reachable with a long ball-end key **without lifting
the board out**, and nothing on the board is above them.

They used to be at ±39.5, which is now **underneath the board** — the rails
reach ±40. The build checks each hole against the board *envelope*, so it
catches that; it caught exactly this when `pcb_tab_w` went in.

Each one is a hole straight through the floor. A bonded seal ("dowty") washer
under each head costs nothing and keeps road spray out of them. A button head sits proud in the strip and fouls
nothing, which is why there is no counterbore; set `floor_hole_cbore_d` if you
want one. Move or add positions in `floor_holes` — the build checks each one
against the PCB footprint, the walls and the screw bosses.

This is a placeholder for a real bracket once the seating position is settled
and it is known where the box can actually live.

## Wire entry — DEUTSCH DT, one footprint for all three sizes

Power and CAN come in through DT flange receptacles ("DT-F") in the end walls,
not through slots. That keeps the wall free of open holes and it keeps
the board's own screw terminals inside, on short pigtails.

The three sizes are interchangeable in this housing, which is worth knowing
because it means one printed part accepts whichever you have in the drawer.
From the TE customer drawings, all of **DT04-2P / -3P / -4P -L012** share the
flange (40.51 × 31.75 × 3.18) and the same four mounting holes on
**30.35 × 22.45** centres — but their recommended cutouts differ:

| | recommended cutout |
|---|---|
| 2 way | 18.42 × 18.29, R5.08 |
| 3 way | round, Ø25.4 |
| 4 way | 22.10 × 20.98, R6.35 |

A **round Ø25.4** hole contains the 4-way's rounded rectangle with 0.09 mm to
spare, so the model cuts one round aperture (Ø25.8 with fit clearance) and all
three drop in. The flange covers it in every case.

### The 8-way — revB, and three numbers that are not confirmed

The keypad build carries eight wires, so it gets one **DT04-08PA-L012** at one
end instead. Connector sizes live in `DT_FOOTPRINTS` and a port names one, so
switching is a one-word edit and the two sizes cannot get their dimensions
crossed.

**Confirmed** from TE's published data:

| | |
|---|---|
| Flange | 54.99 × 35.51 |
| Overall length | 45.67 |
| Contacts | size 16, 9.09 pitch, 4.45 row-to-row |

That mapping was *checked, not assumed*: the same fields on TE's page for the
`DT04-3P-L012` read 40.51 × 31.75, which is exactly the flange this model has
used since day one.

**Inferred, and this is why `verified` is `False`.** TE's customer drawing is
behind a login, so three numbers came from applying the small shell's own
proportions to the bigger flange:

| | | from |
|---|---|---|
| `hole_dx` | 44.83 | 5.08 mm (0.200″) inset per side, as on the 2-4 way |
| `hole_dy` | 26.21 | 4.65 mm inset per side, as on the 2-4 way |
| `aperture` | 38 × 24 R5 | sized to clear the body and keep 3.2 mm of wall to the mounting holes |
| `body_in` | 24.7 | 45.67 − flange 3.18 − the 3-way's 17.85 front end |

**Measure these before printing a box.** They are two minutes with calipers on
the connector and a ruined print if wrong. The build says so on every run, and
`checks()` refuses to be quiet about it until `verified` goes `True`.

The aperture is a rounded **rectangle**, not a round hole — the 8-way's pin
field alone is 27.3 mm wide, so a round hole big enough to pass the body would
be wider than the flange is tall. The first attempt at 40 × 26 left only
1.8 mm of wall between the aperture and the mounting holes; 38 × 24 leaves
3.2, and there is now a check that works that out for any aperture shape
rather than leaving it to be noticed in a render.

### Print `Port-Coupon-dt-8way-revB-8way` first

It is a 67 × 48 patch of the port wall — same 2 mm wall, same 3 mm inner pad,
same aperture, same four holes and nut pockets — so you can test-fit the
connector for 15 cm³ instead of finding out inside a 186 cm³ box. The build
makes one automatically for every unverified footprint, and stops making it
the moment you set `verified` to `True`.

Each port also gets:

- a 3 mm pad on the inside face, so the wall is locally 8 mm — stiffer, and it
  gives the nut pockets a solid floor;
- four Ø4.4 clearance holes (M4, or #8) with hex nut pockets on the inside, so
  the screws have something to bite without loose hardware. Set
  `dt_nut_pockets` to `False` if you would rather use your own nuts and
  washers. Screws need to be ~10 mm to cross the 5 mm wall and pad.

Ports are placed by the `dt_ports` list — label, footprint, wall, position
along it, and height. A height of `None` means **as low as the board allows**,
and the box then grows to cover the flange; that is how revB sizes itself
around the 8-way without anybody doing the sums. The revA default puts power
on one end and CAN on the other, both at z = 28,
which keeps the connector body clear of the board: it reaches 22 mm inboard,
overhanging the end 13 mm of the PCB, and **both end strips of the board were
checked against `rcm.kicad_pcb` and hold nothing but SMD parts** (the USB-C
shell at ~3.2 mm is the tallest). That fact is recorded as `pcb_clear_strip`
and the build warns if a port is moved somewhere it stops being true.

TE sell a gasket that goes between the flange and the panel. Use it.

## The harness off the long edges

Every screw terminal on this board sits on one of the two **long** edges —
`J_CH1`/`J_CH2` on one, `IGN`/`AUX`/`CAN_A`/`CAN_B` on the other — with the
plugs turned so the wires leave the board rather than running back across it.
So the wires have to climb, in the channel between the board edge and the
cavity wall, before they run to a DEUTSCH port in an end wall.

The requirement is **30 mm of clear height above the board's bottom mounting
face** (`wire_clear_h`). That datum is deliberate: it is the face you can
actually get a rule on, unlike the board top or the cavity floor.

The box gives **32.7 mm**, so it clears by 2.7 mm:

```
board bottom face   z =  8.0     floor 3 + standoff 5
plug bodies         z = 18.6     9 mm tall, on top of the board
                    ...          the climb
switch nut, lowest  z = 40.7     <- the ceiling
lid underside       z = 48.0
```

The ceiling is the **corner of the nearest switch nut**, not the lid: at
35 mm row pitch a 32.2 AF nut spans 37.2 across corners, which reaches
|y| = 36.1, and the wires climb outboard of the plug bodies at |y| = 34.2.
`derive()` works that out rather than trusting the number above, and
`checks()` fails the build if it stops being true — so changing the row
pitch, the lid thickness or the standoffs will tell you immediately if it
has eaten the wire space. `images/sections-*.png` draws the channel in green.

It was 1.7 mm when the lid was 6 mm thick. Thinning the lid to 3.5 pushed the
switch deeper, the cavity grew to suit, and the margin came with it. If a fat
cable or a tie-wrap needs more, raise `top_clearance` and everything else
follows.

## The one number to go and measure

`pcb_tall_comp_h` = 12 mm, the tallest thing standing on the board — assumed
to be the Waveshare buck module on its header pins. **It sets the height of
the whole box on its own**, because at 35 mm switch pitch the switches sit
directly over the buck, so the switch tail and the component stack:

```
inner height = standoff 5 + PCB 1.6 + component 12 + switch tail 23.8 + air 2 = 45
```

Measure the real assembly and put the number in. Every millimetre off the
component height is a millimetre off the box.

## The switches

The switch numbers are not new work — they are lifted from
`G:\My Drive\CAD\Exocet\Keypad\Keypad-Face.FCStd`, which was printed and
fitted and worked: Ø25.0 through hole, Ø28.0 head, 35 mm pitch, 2 rows of 4.
The Ø25 hole and the pitch are untouched — do not change them without a test
print. The recess over the head is no longer that part's Ø28.0 × 2.0; see
**The lid is 3.5 mm** below for why it is now Ø28.2 × 0.5.

What did change is how the recess ends. A square shoulder from Ø28 down to
Ø25 leaves a **1.5 mm flat annular ceiling** — printed face down, that is a
horizontal overhang and the one feature on either part that needs support. It
is now a **45° cone** instead: the recess stays full Ø28.2 for its 0.5 mm,
and then the bore closes to Ø25 over the next 1.6 mm at exactly the angle a
slicer will bridge unaided. See `images/bezel_detail-*.png`, which draws the
profile the way it prints.

`sw_bezel_transition` also takes `"radius"` (a quarter-round — softer to look
at, but it runs tangent to the seat, so a narrow ring of it ends up near
horizontal and may want support after all) and `"step"` for the original.

### The lid is 3.5 mm, and the nut is why

It was 6 mm. The nut won the argument: every millimetre of lid is a millimetre
of thread the nut does not get, and 3.5 mm is the most the switch can carry.

It only fits because **`sw_bezel_depth` came down from 2.0 mm to 0.5 mm**. That
number used to be the full head thickness, so the head sat flush. Now it is
only a register: the head lands on its O-ring, the O-ring lands on the 45°
chamfer, and 0.5 mm is all the straight wall needed to locate it. The cone
still gets its 1.6 mm, which leaves 1.4 mm of straight Ø25 bore under it to
line the thread up in.

| | was | now |
|---|---|---|
| Lid thickness | 6.0 | **3.5** |
| Top-face recess | Ø28.0 × 2.0 deep | **Ø28.2 × 0.5 deep** |
| Thread left for the nut | 6.3 | **7.3** |
| Straight bore under the cone | 2.5 | 1.4 |
| Keypad lid volume | 81.5 cm³ | **47.7 cm³** |

The recess is Ø28.2, 0.2 over the Ø28 head, so it drops in rather than being
pressed in. `sw_head_d` and `sw_head_t` now describe the switch head itself,
separately from the recess that takes it — the model needs both to know how
far the head stands proud.

**The head is no longer flush. It stands 1.5 mm proud** (`sw_head_t` −
`sw_bezel_depth`), and a thick O-ring under it will lift it further. That is
what the guard ring has to clear, which is why `guard_h` went to 6.5: the
figure that matters is the **5.0 mm of guard above the button face**, and
`checks()` now enforces that against `guard_min_above_button` rather than
trusting the ring height.

Two things follow from the thinner lid and are worth knowing:

- **The switch hangs 2.5 mm lower into the box** (24.3 mm below the lid, not
  21.8), so the cavity grew to keep it off the buck module. Overall the box is
  still *shorter* — 51.5 mm outside against 52 for the old revA and 54 for
  revB — because the lid gave up more than the box took.
- **Bending stiffness is down about five-fold** (it goes as thickness cubed).
  With no seal to squeeze, that matters less than it would have; it now just
  sets how flat the lid sits on the wall top. revB's 46 mm short-wall span
  helps; revA still spans 92 mm. `screw_extra` takes more positions.

## The start/stop guard

One button — the **front one on the driver's side**, at (−52.5, 17.5) —
starts and stops the car, and it sits where a knee or a sleeve can reach it.

It is at the **front** because the loom arrives from the front of the car and
the DEUTSCH port is on that wall, so the starter is at the same end the wires
come in. `guard_sw` is `("front", "driver")` and `car_front` is `-X`; between
them the pin holes, the checks and the corner coupon all land on the right
corner without a single sign being typed by hand. It gets a raised
collar: Ø38 outside, Ø30 bore, **6.5 mm proud of the lid** — which is
**5.0 mm above the button**, since the head itself now stands 1.5 mm proud. A
fingertip drops straight in; a palm cannot.

**Both top edges are broken at 45°**, 1 mm in the bore and 1 mm on the
outside, leaving 2 mm flat on top of the 4 mm wall. This is the one part on
the whole assembly you are meant to prod at in the dark, so neither edge is
left sharp — the bore edge is what your fingertip slides down, the outer edge
is what the back of your hand catches. `guard_chamfer_in` and
`guard_chamfer_out` set them separately and the build warns if the pair of
them have eaten the wall.

The **base is deliberately left square** against the lid. A chamfer there
would only open a dirt trap round the bond line, and no finger reaches it.

**It is a separate printed part, and that is not laziness.** The lid prints
face down — that is the entire reason the bezel recess ends in a 45° cone
instead of a square shoulder. Anything standing proud of the front face
therefore points straight into the bed. Turning the lid over only moves the
problem onto the 2 mm locating lip, which would then hold the whole lid 2 mm
off the bed with nothing under it. So the ring is its own part, and the lid
keeps its cone, its lip and its face-down print unchanged.

It is located by **two Ø3 × 3 mm pins** into two blind Ø3.2 × 3.5 holes in
the lid, so it cannot be bonded off-centre or crooked and you are not trying
to eyeball concentricity while the glue goes off. The holes leave 2.5 mm of
lid under them and never break through.

The pins sit on a **45° diagonal** (`guard_pin_angle`), which is the furthest
they get from both neighbouring buttons — 10.3 mm of clearance, against
2.4 mm if they were on the X axis. The build checks every pin hole against
every switch recess and every lid screw, so move the guard to another button
and it will tell you if the pins have landed somewhere silly.

**Printing it:** bond face **up** — guard end on the bed, pins printed last.
That is the only orientation in which the pins are not overhangs, and it is
kind to both chamfers as well: printed this way the outer one widens going up
and the bore one closes in going up, both at 45°, so neither needs support
either. It is about 2.5 cm³, so a few minutes.

**Fitting it:** drop the pins in dry first and check the ring is concentric
with the button head before any glue. The Ø30 bore clears the Ø28 head by
1 mm all round, so a rocking ring means a pin is proud, not that the hole is
wrong.

## Corner coupons — the real test print

`Corner-Coupon-Lid-*` and `Corner-Coupon-Box-*` are a **matched pair**: the
corner of the keypad lid nearest the start/stop button, and the top 20 mm of
the box corner it lands on. About 56 × 61 mm, 9.3 cm³ and 12.3 cm³, so the
two together are roughly 27 g — against 12 hours for the box.

Between them they answer everything the flat coupon cannot:

| | |
|---|---|
| **The switch** | Ø25 bore, the Ø28.2 × 0.5 recess, the 45° cone, and whether the nut has thread to grab on a 3.5 mm panel |
| **The guard ring** | both pin holes, so print `Guard-Ring-*` too and check it drops on square |
| **The corner fit** | locating lip into the cavity, lid flat on the wall top, and **two** lid screws into their bosses |

They are **cut out of the built parts by intersection, never modelled a
second time**, so a coupon cannot quietly disagree with the lid and box it is
meant to be testing. Both halves are moved by the same amount in X and Y, so
laid on each other they still line up — `images/corner_coupon-*.png` draws
them mated and exploded.

How far in the cut reaches is worked out, not typed: far enough to swallow
the switch nut, the guard ring and the corner screw boss, plus
`corner_coupon_margin`. Set `corner_coupon_w` / `corner_coupon_d` to override,
and `corner_coupon_box_h` for more of the box than the 20 mm the fit needs.

Print the lid half **face down**, same as the lid; the box half as modelled,
open side up, same as the box.

### The locating lip stops short of the plug

The lip is **cut back either side of every DEUTSCH port** — across the
flange width plus `lid_lip_port_margin` (5 mm). On revB that leaves 14.2 mm
of lip still running at each end of the `-X` wall, so the lid goes on
self-aligning; revA, with a port at both ends, keeps 21.4 mm.

This came off a real print, not out of a check, and the reason no check could
have caught it is worth writing down: **the model draws the receptacle, not
the mating plug.** `dt_body_in` and `dt_body_d` describe the part that is
bolted to the wall. The plug that clips into it, its wedge lock and the wires
sweeping up out of it are not drawn at all. On paper the lip clears the
receptacle by 4.4 mm; in the real box the plug takes that and more.

Cutting only the plug's span, rather than the whole wall run, is deliberate.
Strip the lip from a whole wall and you lose location on that axis; strip it
from two opposite walls and the lid is held by the screws alone, which the
build now warns about. `lid_lip_omit` still takes a list of walls if you ever
want the whole run gone.

Nothing else is affected: with `lid_seal` off there is no groove for the
cutback to interfere with.

### The bosses now bite into the wall

Cutting this coupon turned up a real fault. The lid screw bosses sat exactly
**tangent** to the cavity walls — touching along a line, merged with nothing,
held only by the floor. In the whole box that is invisible, because the floor
ties everything together. Cut the floor away and the bosses fell out as loose
posts.

`boss_wall_bite` (1.0 mm) now sets them that far *into* the wall, so boss and
wall genuinely fuse. The screw moves 1 mm outboard with them — to ±76 / ±46 —
which there is room for, and `checks()` proves it against the groove whenever
`lid_seal` is switched back on. The boss does not reach any further into the cavity than it
did, so nothing near the board changed.

## Flat coupon — the quick one

`exports/Test-Coupon.3mf` is a 35 mm square of the lid: same 3.5 mm thickness,
same Ø25 hole, same Ø28.2 × 0.5 recess, same 45° cone. About 4 cm³, so a few
minutes on the printer, and it answers the three things the full lid cannot
tell you until it is too late:

1. does the cone print clean face down, with no support and no sagging ring;
2. how far does the head actually stand proud **with its O-ring under it**?
   The model assumes 1.5 mm. Measure it, and if it is more, raise `guard_h`
   to keep 5 mm of guard above the button — the build checks that sum;
3. does the nut turn. 35 mm is the switch pitch, and the nut is 32.2 across
   flats but **37.2 across corners**, so on the real lid the nut corners of
   two neighbours nearly meet. The coupon is that spacing exactly.

Set `build_coupon` to `False` once it has served its purpose.

## Printing

**Everything is self-supporting. No supports on any part.**

Box: as modelled, open side up. The DEUTSCH apertures are round, the nut
pockets bridge a short span, and the floor holes are small.

Lids: **face down**, which is the reason for the cone above and gives the
better front surface. The M3 countersinks are 90° included, so they land at
exactly 45° too. The locating lip ends up on the upper side, where it is not
an overhang.

Guard ring: **bond face up** — guard end on the bed, the two pins printed
last. This is the one part whose orientation is the opposite of the lid's,
and it is why it is a separate part at all.

Everything fits an Ender 5 bed.

## Still to do

- Confirm `pcb_tall_comp_h` against the assembled board. revA is built and
  running, so this is now measurable rather than assumed, and it sets the box
  height on its own.
- A real mounting bracket, once the seating position settles. The floor holes
  are a stopgap.
- The relay-control lid is currently just `Lid-Blank`. Its DEUTSCH ports can
  reuse the same aperture footprint as the box walls.
- **Confirm the three inferred `dt-8way` numbers** and set `verified` to
  `True`. Print `Port-Coupon-dt-8way-revB-8way` and test-fit the connector
  before printing a box. This is the biggest open risk in the model.
- revA's short walls still span 90 mm between lid screws. If a revA box leaks,
  that is where. revB is down to 45.
- `wire_clear_h` clears by 2.7 mm. Worth re-checking against the real harness
  with the plugs actually fitted.
- The lid lost about five-sixths of its bending stiffness going 6 → 3.5 mm,
  and the wall is now 2 mm. If the box feels flimsy assembled, `screw_extra`
  is the cheapest fix.
- There is no seal. If this build ever needs one, see **Closing it** above —
  it is a parameter and a thicker wall, not a redesign.

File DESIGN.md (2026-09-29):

# RCM — Relay Control Module (and Keypad, same board)

> **Status 2026-08-04: architecture agreed, nothing drawn yet.** This document records the
> cost analysis that motivated the pivot, the agreed architecture, and what is still open.

## The pivot

`pdm14-revB` switches 14 loads with Infineon PROFET+2 smart high-side switches on the
board. This board instead **drives relay coils** and lets an external relay/fuse box carry
the load current — turning an ordinary automotive relay/fuse box into a CAN-controlled
unit.

## ONE BOARD, TWO ROLES (agreed 2026-08-04)

The same PCB builds as either the **relay control module** or the **keypad node**
(superseding the separate `../keypad` design). This is driven by the qty-1 economics
below: two designs means two fab runs, two stencils, two assembly setups and 10 boards to
get the 2 that are needed — one design means one setup, 5 boards, 2 used, and the spares
are genuinely sellable *because* they are the flexible variant.

It works because the two roles are already the same circuit:

| | Keypad role | RCM role |
|---|---|---|
| output stage | low-side sink → LED− | low-side sink → coil− |
| input stage | button to GND or +12V | coil-return voltage sense |
| MCU, CAN, buck, IMU, terminals | identical | identical |

### The input stage that unifies them

One series resistor + divider to GND per input, plus an **optional pull-up to +12V**
(DNP by default). That single resistor position covers all three cases:

| Pull-up | Reads | Use |
|---|---|---|
| not fitted | 12V = circuit intact, 0V = open | **RCM coil / fuse sense** |
| **fitted** | 12V = open, 0V = pressed | **keypad, earth-switching buttons** |
| not fitted | 0V = open, 12V = pressed | **keypad, positive-switching buttons** |

So earth-switching vs positive-switching **inputs** are a fit/no-fit choice, per channel or
board-wide. That answers the "whole board mode" question for the input side for pennies.

### Outputs are low-side only — and that is the right answer

You cannot get high-side switching out of a sink array; it would need a P-FET plus gate
drive per channel (~$8 for 20, but ~60 extra placements, which matters when hand-building).

**For the RCM role it is moot** — the board drives *coils*, and the relay's own contacts
provide whatever switching polarity the load needs. Coil-drive polarity is invisible to the
load, so "positive switching" is a wiring decision at the relay, not a board capability.

It would only bite driving LEDs directly in the keypad role, and 12V LED rings are
essentially always common-anode (LED+ to 12V, LED− switched) — i.e. low-side. **So:
low-side board-wide, no P-FETs.**

## Where the $500 goes (measured, 2026-08-04)

The revB quote is ~$500 USD for 5 boards. Component prices below are live LCSC/JLC unit
prices pulled 2026-08-04; the fab/assembly figure is the residual.

| | per board | ×5 | share |
|---|---:|---:|---:|
| 15× PROFET (2×BTS7002 @2.88, 4×BTS7008 @0.92, 9×BTS7040 @0.87) | $17.25 | $86 | ~17% |
| STM32F446ZET6 | $5.40 | $27 | ~5% |
| BMI270 IMU | $1.55 | $8 | ~2% |
| microSD socket (DM3AT-SF-PEJM5) | $1.23 | $6 | ~1% |
| SN65HVD230 CAN | $0.48 | $2 | <1% |
| 14× KF301-5.0-2P screw terminals | $0.56 | $3 | <1% |
| everything else (~200 passives, USB-C, EEPROM, LDO, TVS, crystals, terminals, headers) | ~$6 | ~$30 | ~6% |
| **components subtotal** | **~$32** | **~$160** | **~32%** |
| **PCB fab + assembly + setup (residual)** | **~$68** | **~$340** | **~68%** |

### What this means for cost reduction

**The MCU is not the lever.** At $5.40 it is ~5% of the quote. Swapping to an ESP32 saves
maybe $3–4/board — about $20 across the run — while discarding a vehicle-proven firmware
stack and its PC config app. If the MCU changes, the reason should be a *smaller STM32*
(fewer pins, cheaper package, less board area, cheaper to place) rather than a different
architecture.

**The board is the lever.** ~68% of the cost is fab + assembly, driven by:

| Driver | revB | why relays change it |
|---|---|---|
| **Area** | 216 × 148mm = **320 cm²** | no 7mm/2oz output trunks, no EP thermal-via arrays, no M5 stud columns, no 14 large screw terminals |
| **Copper weight** | 2oz outer (required for 21A trunks) | a relay coil is ~150–200mA — 1oz is ample |
| **Layers** | 4 | plausibly 2 once the high-current pours are gone |
| **Surface finish** | ENIG (required for the bolted M5 stud joints) | no studs ⇒ HASL is fine |
| **Placements** | **315 per board** (1575 for the run) | a PROFET channel carries RS/RP/DZ/CS/RG/RIP/CO/CV; a relay channel is a low-side FET + gate resistor + flyback, or one octal driver per 8 channels |

Attacking area, layer count, finish and placement count together is where the real
reduction is. The PROFET removal ($17.25/board) is a genuine saving but is second-order
next to the board itself.

## What is being given up, and what has to be replaced

Relays are not drop-in equivalents to smart high-side switches. Going in with this
explicit:

| PROFET feature | Relay equivalent |
|---|---|
| Per-channel **current sense** (`IS` pin, `kILIS`) | **dropped deliberately** — the fuses do overcurrent. See the coil-circuit sense below, which is a continuity check, not a measurement |
| Open-load detection | replaced by **coil-circuit sense** (below), which detects a broken coil circuit but not a broken *load* |
| **PWM / soft-start** | not possible on a mechanical relay |
| Overcurrent / overtemp / short-circuit shutdown | delegated to the **fuse box's fuses** |
| Reverse-polarity, ~35V clamp per channel | delegated to input protection |
| Silent, unlimited switching cycles | relays have finite contact life and audible click |

The fuse box handling overcurrent is arguably the point: fuses are cheaper, field
replaceable, and understood by anyone working on the car.

## Firmware scope (user, 2026-08-04) — deliberately much smaller than SynapsePDM

The functional requirement is **"turn things on and off via CAN, plus put IMU data on
CAN"**. That is it. Route is undecided between **butchering joesbox's firmware down to
that** and **writing something simple in the Arduino IDE**.

**This is the decision that reframes the MCU choice.** The earlier argument for staying on
an STM32F4 was firmware reuse — if the firmware is a few hundred lines either way, reuse
stops being the constraint and the MCU should be chosen on cost, size and CAN support.

What is still worth preserving regardless of chip or language: **CAN message compatibility**
with the existing DBC (`../SynapsePDM/SynapsePDM/CAN DB/`) and the Cortex PC app, so the
`../keypad` node and any existing tooling keep working. Message layout is cheaper to keep
than to re-invent, even in fresh firmware.

### MCU options at this scope (live prices 2026-08-04)

| Part | Price | Package | Notes |
|---|---:|---|---|
| **STM32F103C8T6** | **$1.04** | LQFP-48 7×7 | bxCAN on-chip, Arduino via STM32duino, 214k stock. 64KB flash is ample for this scope. Cheapest and smallest |
| STM32F446RET6 | $4.93 | LQFP-64 10×10 | only worth it if joesbox's firmware is kept substantially intact |
| STM32F446ZET6 | $5.40 | LQFP-144 20×20 | revB's part. No reason to carry 144 pins here |
| ESP32-WROOM-32E-N4 | $3.34 | module 25.5×18mm | **more expensive than the F103, and physically much larger.** One placement, native Arduino, TWAI CAN, and WiFi/BT if wanted |

**The ESP32 is not the cost win it looks like** — it is 3× the F103's price and takes far
more board area, which is the thing actually driving cost here. Pick it for WiFi/BT as a
feature, not to save money. Both still need an external CAN transceiver.

### MCU: STM32 base + an OPTIONAL ESP32-C3 co-processor (decided 2026-08-04)

At qty 1 the spread between all these parts is **~$2 on the whole project**, so cost is a
non-criterion. Two earlier arguments are withdrawn:

- ~~"Pick G431 for commonality with the keypad."~~ **Retracted** — that rested on the keypad
  being fixed, and it is not; the keypad is being folded into this board instead.
- ~~"STM32 is the more performant part."~~ **Not true.** The classic ESP32 is 240MHz
  dual-core with 520KB RAM against an STM32G431's 170MHz single M4 with 32KB.

Where STM32 actually wins is I/O *quality*, not capability: **5V-tolerant pins** (ESP32 has
none), a far better ADC, **mature CAN** (bxCAN/FDCAN vs ESP32's TWAI, which has an errata
history), and deterministic timing that the ESP32's RF stack can disturb. For switching
relays only the CAN maturity and 5V tolerance really matter.

**So do not choose.** Put an STM32 on the board for the reliable CAN/relay job, and add a
footprint + UART header for an optional **`ESP32-C3-MINI-1-N4`** (`C2838502`, $2.79,
16.6×13.2mm, 16k stock) as a WiFi/BLE co-processor. Fitted only when wireless is wanted, a
4-pin header otherwise. Costs almost nothing unpopulated, and it means the wireless
question does not have to be settled before layout.

Note the specific STM32 is still open — with shift registers absorbing the I/O, the part
only needs CAN, ~6 pins for the register chains, I2C/SPI for the IMU, and SWD. Almost
anything qualifies, so pick on toolchain preference.

### Phone-as-key — deliberately a SEPARATE future node, not this board

Feasible and wanted, but kept off the RCM for three reasons:

1. **It is a security function on a body controller.** The RCM should stay a dumb, reliable
   actuator. Far better for an auth node to publish an authenticated "unlocked" message on
   CAN and let something else gate ignition.
2. **BLE proximity is relay-attackable** — the well-known passive-keyless-entry attack.
   Bare RSSI proximity is not enough; it needs challenge-response with a shared secret, and
   ideally an explicit app action rather than "phone is near".
3. ~~NFC has an iOS problem.~~ **RESOLVED 2026-08-04: the user is on Android**, where host
   card emulation works properly. So **NFC is viable and is the preferred route over BLE** —
   centimetre range makes it inherently resistant to the relay attack in (2), and tapping is
   a deliberate act rather than passive proximity.

**The real blocker is power, not the radio.** Phone-as-key needs something permanently
awake, which fights the parked-off architecture. An ESP32-C3 duty-cycling BLE is ~10–100µA
— negligible against a ~50Ah battery — but the **buck module's quiescent draw will dominate
and is likely milliamps**, i.e. ~1–2Ah over a fortnight. The always-on portion needs its own
low-Iq rail. That is a further argument for making it a small separate node.

## Quantity: these are ONE-OFFS (user, 2026-08-04)

**Not production, not for sale — ideally one of each board.** This changes the objective
function, and it retires several earlier concerns.

Per-unit BOM cost is now nearly irrelevant. At qty 1 the cost is dominated by:

1. **Board area** — fab is priced by area, so shrinking the outline is still the top lever.
2. **Layer count, copper weight, surface finish** — 2-layer / 1oz / HASL vs revB's
   4-layer / 2oz / ENIG.
3. **Number of unique *extended* parts** — JLC charges a per-unique-extended-part handling
   fee, which is a fixed cost paid once no matter how few boards you build. **revB has 33
   extended lines out of 59.** Consolidating values and preferring Basic/Preferred parts is
   a real lever at qty 1 that did not matter at volume. (Check JLC's current fee schedule —
   the terms change — but the structure holds.)
4. **Placement count and fixed setup/stencil fees.**

⚠ **You cannot actually order one.** JLC's PCB minimum is typically 5 pcs (sometimes 2) and
PCBA minimum around 2. The practical shape is: fab ~5, **assemble 1–2, keep the rest bare
as spares** — you only pay components and placement for what is assembled.

**Worth evaluating for this board specifically: skip PCBA and hand-build.** The RCM should
land near ~100–150 placements (against revB's 315), which is a long evening by hand and
removes the assembly and per-part fees entirely. A middle option is JLC placing the
fine-pitch SMD and hand-fitting the THT connectors, which JLC surcharges anyway.

### Concerns this retires

All the stock-depth caps flagged earlier were volume constraints and are now moot:
BTS7008 (10 boards), BTS7002 (36), and **TPL7407L's thin 32–48 unit stock** — needing 3
chips for one board makes it a non-issue.

## Relay drive: the saving is larger than the PROFET line suggests

A MOSFET sink array replaces both the switch **and** the flyback diodes:

| | revB | RCM |
|---|---|---|
| switching | 15× PROFET, **$17.25** | 3× **TPL7407L** (21 ch), `C2149827`, $0.39 ea = **$1.17** |
| flyback | n/a | **integral** — the array's `COM` pin clamps every channel, so ~20 discrete diodes disappear |
| per-channel support parts | RS/RP/DZ/CS/RG/RIP/CO/CV | none |

### DECIDED: TPL7407L, not ULN2803 — the Darlington cannot hold all channels on

The user flagged this and was right. Relay coils are ~150–200mA each, unlike the keypad's
LEDs, and that is where the Darlington falls over:

| | ULN2803A (**8**ch, SOP-18) | **TPL7407L** (**7**ch, TSSOP-16) |
|---|---|---|
| drop @ 200mA | 1.1–1.6V `Vce(sat)` | ~0.1–0.25V (MOSFET) |
| per channel | ~0.26W | ~0.05W |
| **all channels on** | **~2.1W ⇒ ~200°C rise** — not survivable | ~0.35W — fine |
| 3.3V logic drive | input resistors sized for 5V, needs checking | explicitly 3.3V-friendly |

`TPL7407LAPWR` = `C2149827`, $0.39, TSSOP-16. Note it is **7-channel** (a ULN2003
replacement, not ULN2803), so **3 chips give 21 channels** for $1.17. Stock is thin
(32–48 units per variant) but irrelevant at qty 1.

**The keypad role uses the same TPL7407L** (superseding the earlier note that the standalone
`../keypad` board keeps its ULN2803A — that board is being folded into this one). Two
reasons beyond dissipation: the **ULN2803's input resistors are sized for 5V logic**, so
3.3V drive is marginal at coil currents, and the socketed-DIP rationale no longer applies
now that a specific package is not required. One driver part covers both roles.

## Channel count: target 18–20 (user, 2026-08-04)

"Aim for 18–20 outputs; pull back if something doesn't work." With `TPL7407L` being a
**7-channel** part, 3 chips = **21 channels**, which covers the target with one spare.

**I/O expansion makes the count cheap to change.** 20 outputs + 20 fuse-sense inputs = 40
I/O, which no LQFP-48 provides alongside CAN and a crystal. Use shift registers —
`74HC595` for outputs, `74HC165` for sense inputs (`C22384789`, $0.065, 3.7k stock) — and
channel count decouples from MCU pins entirely. Scaling 20 → 16 then becomes a board-space
decision, not a re-architecture, which is exactly the flexibility the target asks for.

### Channel plan: 21 UNIVERSAL channels (revised 2026-08-04)

Supersedes an earlier "21 outputs + 16 separate inputs" plan. **Every channel's terminal
serves as either an output or an input**, because the sense node *is* the driver node and a
`TPL7407L` output is open-drain — a channel that is never driven simply floats, and the
terminal behaves as a pure input:

| Build | Pull-up | Terminal behaves as |
|---|---|---|
| RCM coil | not fitted | driven output + coil-circuit sense |
| Keypad LED | not fitted | driven output |
| Keypad button | **fitted** | input; driver never driven for that channel |

This removes ~16 terminal positions and drops the shift registers from 8 to 6. The only
cost is the driver's off-state leakage (~µA) sitting on an input node — negligible. If
firmware ever drives a channel wired as a button, the pull-up simply sources ~12µA to
ground; harmless.

**Final channel plan:**

- **21 universal channels** — 3× `TPL7407L` (7 each)
- **3× `74HC595`** (24 outputs, 21 used)
- **3× `74HC165`** (24 inputs — 21 channels + 3 dedicated board inputs e.g. ignition sense)
- per channel: 2 divider resistors + 1 **optional** pull-up

RCM role uses all 21 as outputs; keypad role uses ~8 as LED outputs and ~8 as button
inputs, from the same 21.

### Three identical 7-channel tiles

The above falls out naturally into **three identical tiles**, each = 1 `TPL7407L` +
1 `74HC595` + 1 `74HC165` + 7 channels' dividers + 7 terminal positions. The tiles
daisy-chain on a 3-wire shift-register bus.

This is the concrete form of the routing argument for keeping shift registers: each tile's
registers sit **directly behind the terminals they serve**, so only 3 signals cross between
tiles instead of 21+ radiating from a central QFP. It is what plausibly keeps the board at
**2 layers**, and it makes layout a copy-paste of one tile — the same approach that worked
on `pdm14-revB`'s channel clusters.

## Assembly: PCBA, with 0805 passives for repairability (decided 2026-08-04)

**JLC PCBA, not hand-build.** ~300 hand joints on a 21-channel board is ~300 chances for a
cold joint to hunt down later, and PCBA makes the `ESP32-C3` module and any fine-pitch part
trivial to fit.

**Passives are 0805, not 0402 — deliberately.** Costs ~8% of component area, accepted by
the user so that a failed part can actually be replaced by hand. Consistent with the
serviceability bias applied throughout this project.

⚠ **The screw terminals and buck header pins are THT**, which JLC surcharges and restricts.
Plan on the realistic split: **JLC places all SMD, the THT terminals are hand-fitted.** That
is a handful of easy joints, not 300 — but do not assume "PCBA" covers the whole board.

**Minimise *unique* part numbers, not part count.** At qty 1 the per-unique-extended-part
fee is a fixed cost, so the divider network should use only 2–3 distinct resistor values
across all 24 inputs, and one terminal family throughout.

### Reconsidered and kept: shift registers over a big MCU

PCBA removes the "fine-pitch is hard to solder" objection, so a single LQFP-100 STM32
(~80 GPIO) could drive all I/O directly and delete the 6 registers — marginally fewer
unique parts and slightly less area. **Kept the registers anyway** for the routing/2-layer
reason above. Revisit for a rev B of this board once the first one is built and the real
routing density is known.

## Floorplan and size estimate

Component area at 0805, roughly:

| | area |
|---|---:|
| ~30 terminal positions (3.5mm pitch × ~10mm deep) | ~1050 mm² |
| Waveshare buck module (33×16 + clearance) | ~600 mm² |
| 6 shift registers + 3 drivers + MCU + CAN + IMU | ~670 mm² |
| optional `ESP32-C3` module | ~220 mm² |
| ~72 divider/pull-up resistors + decoupling @ 0805 | ~460 mm² |
| misc (protection, LDO, crystal, LEDs, SWD) | ~200 mm² |

≈ **32 cm²** of parts; at a typical 2–3× for routing and spacing that lands around
**70–100 cm², i.e. roughly 100 × 80mm** — against revB's 216 × 148mm = 320 cm², a ~4×
reduction. Note this comes mostly from losing the high-current copper, not from PCBA.

Proposed edge allocation:

| Edge | Contents | positions |
|---|---|---:|
| South | 3 channel tiles × 7 | 21 |
| West | power in (2) + commons +12V/GND for keypad LED+/switch returns (4) | 6 |
| East | CAN in/out (2× 3P, daisy-chain) + 3 dedicated inputs | 9 |
| North | buck module + `ESP32-C3`, no terminals | — |

~36 positions ≈ 126mm of terminal edge against ~360mm of perimeter — comfortable, which is
why spreading across edges matters more for grouping than for fit.

### Why shift registers and not a resistor ladder

Asked and worth recording. **The decisive reason is simultaneity, not level shifting.** A
ladder encodes N switches as N voltage levels on one ADC pin, so two closed at once gives an
ambiguous middle voltage. Both roles need all states at once — a keypad must handle
multi-button presses, and the RCM must continuously read 21 independent coil states. A
ladder fundamentally cannot do that.

Secondary: with a 3.3V ADC and 16 levels each step is ~200mV, which is uncomfortably tight
against resistor tolerance and automotive noise on long wires, whereas a digital threshold
just has to be crossed. And a ladder needs precision resistors anyway, so it is not even
cheaper than a $0.065 register. The per-input divider is needed either way — the register
replaces the *discrimination* scheme, not the level shift.

⚠ `74HC165` inputs are **not Schmitt-triggered**, so heavily RC-filtered inputs give slow
edges. Fine in practice here (transitions are infrequent and firmware debounces anyway),
but if bench testing shows chatter, a `74HC14` Schmitt buffer ahead of it is the fix — do
not blame the wiring first.

## Connectors: 3.5mm pluggable, spread over multiple edges (2026-08-04)

User: smallest sensible edge terminals, **not** revB's power-handling blocks, and spreading
across 2–4 edges to shrink the board is fine.

**Family: `KF2EDG` / `15EDG` 3.5mm pluggable** — a board header plus a removable screw plug:

| Part | LCSC | Price |
|---|---|---|
| `KF2EDGVM-3.5-2P` board header | `C441407` | $0.12 |
| `KF2EDGK-3.5-2P` screw plug | `C440847` | $0.18 |

3.5mm pitch, ~8–10A, 16–24AWG — right for coil, LED and button wires, and far smaller than
revB's 5.0mm KF301 power blocks. **The pluggable part matters more than the size**: the
whole loom unplugs from the board for service, consistent with how the rest of this project
is built.

Density is not the constraint — 3.5mm × ~40 positions is ~140mm of edge against ~360mm of
perimeter on a 100×80mm board. **Spread across 2–3 edges anyway** and group by function
(outputs one edge, inputs another, power/CAN a third) rather than purely to save space.

## Fuse/coil-circuit detection — user's idea, adopted (2026-08-04)

**The idea:** feed the relay coil from the *fused* terminal and have the board switch the
coil's ground, so a blown fuse is detectable.

**It works, and needs no extra wires.** Sense the low-side switch drain — the coil-return
wire already present. With the channel OFF no current flows, so there is no drop across the
coil and the node sits at rail voltage; the sense divider's lower leg doubles as the
pulldown that defines 0V when the feed is dead. **Two resistors per channel plus one
`74HC165` input, ~$0.15 for all 20.**

Four constraints:

1. **Off-state diagnostic only.** With the channel on, our own switch holds the node near
   0V. Every *off* channel can be monitored continuously; a channel cannot be tested while
   driving.
2. **It detects any coil-circuit break** — blown fuse, missing relay, open coil, broken
   wire. Report it as *coil circuit integrity*, not "fuse blown".
3. **⚠ Topology is the real risk — verify against the actual box before committing.** This
   requires the fuse **upstream**: battery → fuse → relay pin 30, coil fed from that same
   fused node. Many relay/fuse boxes instead run relay pin 87 → fuse → load; there the coil
   could never get power to close the relay in the first place (chicken-and-egg) and the
   scheme does not work.
4. **Parked drain.** A 100k/22k divider is ~0.1mA/channel, ~2mA over 20 channels,
   permanently. The revB ignition latch exists precisely to kill that, so use ~1M/220k
   (~0.24mA total) or feed the dividers from the switched rail.

Side effect to be aware of: with the coil on the fused node, a blown fuse drops its own
relay out immediately. Probably a safety plus, but it is a behaviour change.

## MCU: STM32F446RET6, LQFP-64 (decided 2026-08-05)

Same silicon as revB, quarter the area of its ZET6. The user asked whether reusing revB's
chip was worth it "if more capable and roughly the same cost" — both true, but **the cost
that matters here is area, not dollars**: LQFP-144 is 20×20mm = 400mm², ~5% of an ~80cm²
board, plus ~11 VDD decoupling caps and heavy fanout, and it buys nothing because the shift
registers already absorb the I/O. The RET6 is 10×10mm at $4.93.

Why the F446 family over the G431 otherwise preferred:

- **SDIO.** Confirmed present on the die (CMSIS header: `CAN1`, `CAN2`, `USB_OTG_FS`,
  `SDIO`). G431 has none — SD would be SPI-mode only. Keeps microSD cheap while it survives.
- **USB and CAN coexist.** This rules out the F103 floated earlier at $1.04: on F103 they
  **share the same SRAM buffer and are mutually exclusive**, and USB-C is on the keep-list.
- Butchering joesbox's firmware becomes a pin remap rather than a port.

⚠ Verify against DS10693 before drawing that LQFP-64 breaks out USB OTG FS, CAN *and* SDIO
without conflict; fallback is **F446VET6** (LQFP-100, 14×14mm).

## Latch part: BTS7040, not BTS7008 (asked and checked 2026-08-05)

User suggested a BTS7008 on the grounds that tiny current means no heating and therefore no
heavy pours. The goal is right; the swap is not needed, and the part ordering runs the other
way.

**The digits are roughly Rds(on) in mΩ** — BTS7002 = 2mΩ/21A, BTS7008 = 8mΩ/11A,
BTS7040 = 40mΩ/4.5A. Lower number = beefier. 7040 → 7008 is moving *up*.

The latch feeds only the buck (coil current comes from the fuse box), so it carries
~65–165mA:

| | dissipation @165mA |
|---|---:|
| BTS7040 (~40mΩ, ~60mΩ hot) | **1.6 mW** |
| BTS7008 (~8mΩ) | 0.3 mW |

1.6mW in a TSDSO-14 is a couple of degrees — **no pour needed either way, 2-layer is safe**.
Prices are a wash ($0.867 vs $0.924). Keeping the 7040 because revB proved this exact
circuit with that part's `IN` thresholds and divider values; swapping means re-verifying
them for zero gain.

## Feature priority (user, 2026-08-05)

Keep-order: **IMU (non-negotiable) > ignition latch > USB-C > EEPROM**. microSD and SIM7600
are lower value — but the user's call is to **design them in now and delete later if space
demands**, on the principle that simplifying is easier than adding.

Endorsed, with one practical condition: the droppable blocks go in a **physically separable
corner** so deletion does not ripple through the floorplan. Note microSD is not free even
when fitted — it drags back the no-RTC logging problem, since there is no backup cell.

The latch **cannot** be built from a `TPL7407L` channel, as asked: the latch switches the
+12V feed to the buck, which is high-side, and a sink can only pull a P-FET gate — which is
exactly revB's deleted `Q3` bug (source on +12V_P, gate to ground = full rail across Vgs,
−14.4V against ±12V abs max). Use the PROFET; its `IN` is ground-referenced so the problem
does not exist.

## Commons come from the loom (user, 2026-08-05)

Confirmed: the board is an **earth-switching and sensing mechanism**. Coil+ comes from the
fused terminal in the box; keypad LED+ comes from the loom at the button. No +12V
distribution terminals.

**One exception: GND stays on the CAN connector.** That is a signal reference, not power —
CAN transceivers' common-mode range depends on nodes sharing a ground. Spare GND positions
for switch returns are optional: at 12µA through a 1M divider, a 0.5V chassis-ground offset
maps to ~0.09V at the logic pin, so chassis-grounding switches is fine.

## Open decisions

1. ~~**`TPL7407L` input pulldowns**~~ — **ANSWERED on revA, 2026-08-27. No pulldowns
   needed.** With a relay on channel 21, neither five MCU resets nor a full cold start
   (`J_PWR` pulled and reconnected) produced a single click. `SR_OE_N` is held high by
   `R_OE` while the MCU pin is high-impedance, so the `74HC595` outputs really were
   tri-stated and the driver's inputs really were floating -- and the part holds them low
   itself. The cold start additionally covered the rail ramp, where the shift registers
   come up with undefined contents before `R_OE` can hold `OE_N` high.
2. **LQFP-64 pinout** — USB/CAN/SDIO coexistence, above.

### Settled

- **One board, two roles** — RCM and keypad build variants of the same PCB.
- **No load current sensing** — the fuses do that job. Coil-circuit sense is *not* a
  current measurement.
- **Driver: TPL7407L** ×3 (21 channels), not ULN2803 — dissipation *and* 5V-logic inputs.
- **Outputs low-side only**; switching polarity comes from the relay contacts.
- **Inputs switchable** earth/positive via an optional pull-up resistor.
- **Channel plan: 21 UNIVERSAL channels**, each terminal an output or an input.
- **Three identical 7-channel tiles** (driver + 2 registers + 7 channels each).
- **I/O via `74HC595`/`74HC165` shift registers**, not a resistor ladder — kept over a
  big-pin-count MCU for routing/2-layer reasons; revisit for a rev B.
- **PCBA (not hand-build), 0805 passives** for repairability; THT terminals hand-fitted.
- **Phone-as-key uses NFC, not BLE** (user is on Android) — still a separate node.
- **Connectors: `KF2EDG` 3.5mm pluggable**, multiple edges.
- **Buck: Waveshare DC5-36-TO-DC3V3-5** from revB (not the keypad's WeAct), socketed.
- **MCU: STM32F446RET6** (LQFP-64), plus an optional `ESP32-C3-MINI-1` co-processor.
- **Latch: one `BTS7040-1EPA`**, revB's circuit verbatim, driven by a DIRECT MCU GPIO.
- **Commons from the loom**; only CAN keeps a GND pin.
- **Phone-as-key: separate future node**, not this board.

### Relay box — no longer a gating unknown

The fuse-sense topology risk is resolved: the box is **fully re-pinnable** (currently a
Haltech, possibly replaced or self-built), so the required arrangement — battery → fuse →
relay pin 30, coil fed from that same fused node — can simply be wired that way.

## Parked

- `5.0SMDJ20A` (`C2990361`), the revB load-dump TVS on `D15`/`D16`, went to **0 stock** at
  JLC on 2026-08-04. Not urgent — the revB order is on hold pending this board — but it
  needs a substitute before that BOM is ever uploaded.

## Carried over

See `CLAUDE.md`: BMI270 IMU, the Waveshare DC5-36-TO-DC3V3-5 buck module and its pin
arrangement (socketed), CAN as the control bus, and the SynapsePDM firmware lineage.

## Part sourcing — the four substitutions (2026-08-06)

Sourcing the BOM against JLC's live catalogue forced four changes to what the design first
called for. All four are folded back into `gen_spec.py`, so the schematic, the netlist and
the BOM agree — nothing lives only in `jlc_parts.json`.

**The governing economics:** at qty 1 (min order 5) the per-unique-*extended*-part fee is a
fixed cost, and this BOM has ~48 lines. Those fees, not unit prices, dominate the build. So
a JLC **Basic** part is worth taking even when it costs several times more per piece — the
74HC595 is the clean example: basic SOIC-16 at $0.171 against $0.044 for the cheapest
extended SOP-16, which is 39 cents more across three chips against a fee many times that.

| Was | Now | Why |
|---|---|---|
| LD1117S33 | **AMS1117-3.3** (`C6186`) | Basic part. Both KiCad symbols `extends "AP1117-15"`, so pin-identical by construction; same SOT-223, tab on pin 2. 5V in leaves 1.7V over a ~1.3V dropout. |
| 25LC640 | **M95640** (`C283461`) | $0.33 against $0.73–1.42, and better stocked. Same industry-standard 25-series SPI pinout, which is exactly what the generic `Memory_EEPROM:25LCxxx` symbol describes — symbol and nets unchanged. |
| 12pF crystal load caps | **20pF** (`C1798`, basic) | Not a cost change — the 12pF was **wrong**. See below. |
| 30V PPTC | **60V PPTC** (`C19078719`) | The SMAJ33A clamps near 53V. A 30V fuse sits under its own clamp. |

### The crystal load caps were wrong, and it was the RTC that suffered

Load caps follow `C = 2 x (CL - Cstray)`. The chosen 32.768kHz part (`C32346`, Epson
Q13FC13500004) is a **CL = 12.5pF** crystal, so with ~3pF of stray it wants **~19pF** —
not the 12pF the design had. 12pF leaves the loop about 3.5pF light, which pulls the
oscillator roughly **22 ppm fast: about a minute a month**, on the one oscillator whose
entire job is keeping time. Given how much of the revB review turned on RTC behaviour,
that was worth catching before ordering rather than after.

20pF fixes it to within a few ppm **and deletes a BOM line**, since the 8MHz already used
20pF — one fewer unique part fee.

The 8MHz keeps 20pF against its own 20pF CL, which runs it ~60ppm fast. That is nothing
beside CAN's ~1% and USB FS's 2500ppm budgets, and light load caps only *improve* startup
margin. 33pF would be exact if it ever matters, at the cost of a BOM line.

### The package trap the composite key caught

`jlc_parts.json` is keyed `value|footprint`, not by value. That is what the BOM script
looks up — keyed by bare value it silently matches nothing and every line comes out
unsourced, which is how the map was first written and would have produced an empty BOM.

The key also guards the package, and it earned that immediately: the cheapest **basic**
8MHz crystal (`C12674`) is **HC-49S-SMD**, which would not have fitted the 5032 lands on
this board. The 5032 basic part (`C115962`) costs more and is the correct one.

### Two lines worth knowing about

- **`RESET` switch (`C2886894`, TL3342) is $1.13 with only ~455 in stock** — easily the
  weakest line in the BOM. A cheaper tactile switch needs a different land pattern, so it
  is a next-revision change rather than something to force now. The button is not required
  to program the board: NRST is on the SWD header.
- **`USB-C` (`C165948`, TYPE-C-31-M-12) needs its land confirmed** against the
  `USB_C_Receptacle_HCTL_HC-TYPE-C-16P-01A` footprint. The two are widely treated as
  interchangeable, but that is received wisdom, not something checked against a drawing.

### Status LEDs run dim, deliberately

Green LEDs are InGaN with a Vf around 3.0–3.2V at rated current, so on a 3.3V GPIO through
1k there is very little headroom — perhaps 0.7mA once Vf falls at low current. Visible, but
dim. Dropping `R_LED1`/`R_LED2` to 470R (or reusing the 120R already in the BOM) would fix
it; 120R costs no extra BOM line but pulls ~11mA on the red. Left at 1k because the
indicators sit under the button panel anyway — worth revisiting if they end up exposed.

### 270k stays extended

There is no basic 270k in 0805, and none at 300k or 330k either, so there was no basic part
to move the sense divider *to*. The verified 1M/270k ratio stands rather than being bent
toward a part that does not exist.

## Channel mode became a software table, not hardware (2026-08-06)

The plan to make each channel switchable in hardware — 21 DIP switches, a readback, a
south-half re-layout — was **abandoned, and the board got simpler instead.**

### What I had wrong

The problem was only ever the pull-**up**. `R_PU` fitted as a 10k pull-up to +12V makes a
blown fuse read 2.531V and a good one 2.551V — both HIGH, 20mV apart. Fuse sensing dead.

A 10k pull-**down** does not do that, because the ~85 ohm relay coil completely swamps it:

| Channel state | Divider | Reads |
|---|---|---|
| Output, driver off, fuse GOOD | 2.530 V | HIGH |
| Output, driver off, fuse BLOWN | 0.000 V | LOW |
| Input, button open | 0.000 V | LOW |
| Input, button closed to +12V | 2.551 V | HIGH |

All four correct **with the same resistor fitted on every channel**. Nothing is
mode-dependent, so there is nothing for hardware to select. `R_PU` is now a fitted 10k to
GND on all 21 channels, and in/out is purely a firmware table.

That deleted the DIP array, the readback, the P-FET rails and the re-layout in one go.

### The trade: buttons are positive-switched

Wired to +12V rather than to ground. Two consequences, both improvements:

- **Wetting current 1.20mA**, against 0.0094mA if the sense divider alone were the
  pull-down. That is the difference between contacts that stay good and contacts that go
  intermittent.
- **Chafe is fail-safe.** A button wire rubbing to chassis reads *not pressed*. Earth
  switching reads *pressed* — a phantom activation. The feed to the buttons wants its own
  small fuse.

Standing draw is 25mA with all 21 idle-high; the 1.19mA through an idle coil is far under
the ~100mA a relay needs to pick up.

## Config DIP switch (`SW_CFG`)

One 8-way 1.27mm half-pitch switch (`C6386921`) in the top-right corner — the only free
10x10mm pocket on the board, and conveniently next to `J_CAN2` where the termination pole
has to reach. Switch *k* pairs pins *k* and *(17-k)*, verified off the symbol's own pin
geometry rather than assumed.

| Pos | Function | How |
|---|---|---|
| 1 | **CAN termination** | Passive, parallels `R_TJ` |
| 2 | **Role** — RCM or keypad | PC0 |
| 3 | **Address bit 0** | PC1 |
| 4 | **Address bit 1** | PC2 |
| 5 | **CAN bitrate** 500k/1M | PC3 |
| 6 | **IMU publish enable** | PC4 |
| 7-8 | unconnected | — |

Positions 2-6 use the STM32's **internal** pull-ups, so each switch just shorts a GPIO to
ground — no external resistors. Closed = 0.

**Why these settings and not others:** everything except the IMU bit is something you cannot
fix over the bus once it is wrong — termination, node identity and bitrate all have to be
right *before* CAN talks at all. The IMU bit is there because only one board in a car should
publish orientation, and a keypad bolted into a door card is not that board.

Termination keeps `R_TJ` in parallel deliberately: the DIP for the bench, a soldered 0R for
the car, where a mechanical contact carrying ~17mA could chatter under vibration.

### Positions 7 and 8 are unconnected on purpose

Routing two more nets from the top-right corner across the CAN/IMU corridor to the MCU is
what tipped this board from routable to not — first 3 nets failed, then 1. Dropping the two
spare bits fixed it outright. The switch positions still physically exist for a future
revision; only the copper is gone.

**Verify the DIP land before ordering.** The footprint is the standard 1.27mm 8-position
gull-wing (7.62mm row spacing); `C6386921` was not checked against a dimensioned drawing.
Same caveat as the USB-C.

## Temperature audit — the board is a +70C board (2026-08-08)

Prompted by the question: if one part is rated lower than the rest, that part sets the
board's limit. Correct, and worth doing properly rather than spot-checking. Every line
audited against its JLC datasheet range:

| Limit | Parts |
|---|---|
| **-20 .. +70C** | `SW_RST` TL3342 tactile switch |
| **-30 .. +80C** | `J_USB` TYPE-C receptacle |
| **-40 .. +85C** | `U_MCU`, `U_IMU`, `U_CAN`, `U_EEP`, `U_SI1-3`, `Y1`, `Y2`, `F1` |
| -30 .. +85C | `D_LED1`, `D_LED2`, `SW_CFG` |
| -40 .. +105C | all three terminal blocks |
| -40 .. +125C | `U_DRV1-3`, `U_SO1-3`, `U_LDO`, `D1` |
| -55 .. +155C | every resistor |
| -40 .. +175C | `U_LATCH` |

Capacitors are not stated in JLC's description but follow their dielectric: **X5R is +85C**
(`C_3V3I`, `C_5V`, `C_MB`, `C_VCAP`), **X7R and C0G are +125C** (`C_3V3O` and the other
100nF, `C_BULK`, the crystal load caps).

**So the board is -20 .. +70C, set by the reset switch**, and -30 .. +80C once that is
discounted. A cabin in direct sun can reach 60-80C, so this is not academic.
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

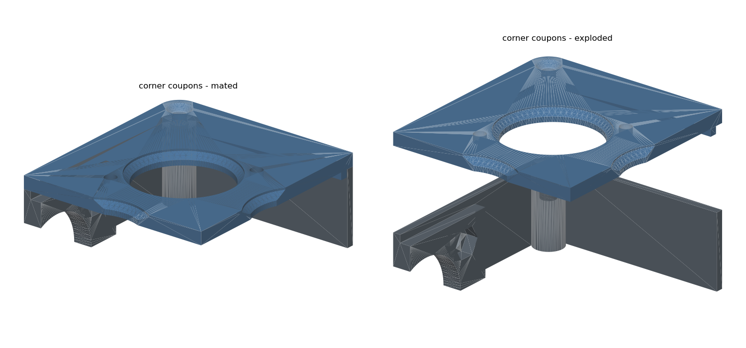
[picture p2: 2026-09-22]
enclosure/images/corner_coupon-revA.png

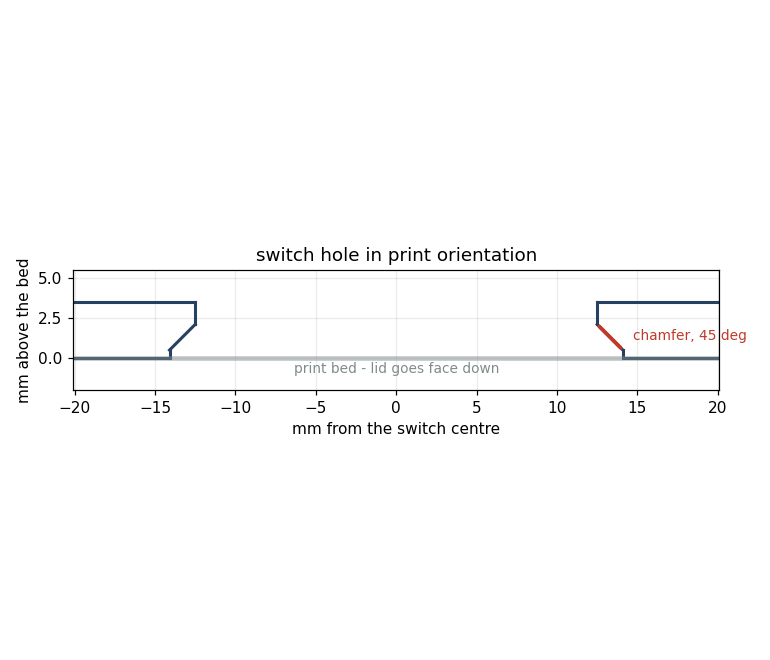
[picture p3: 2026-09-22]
enclosure/images/bezel_detail-revA.png

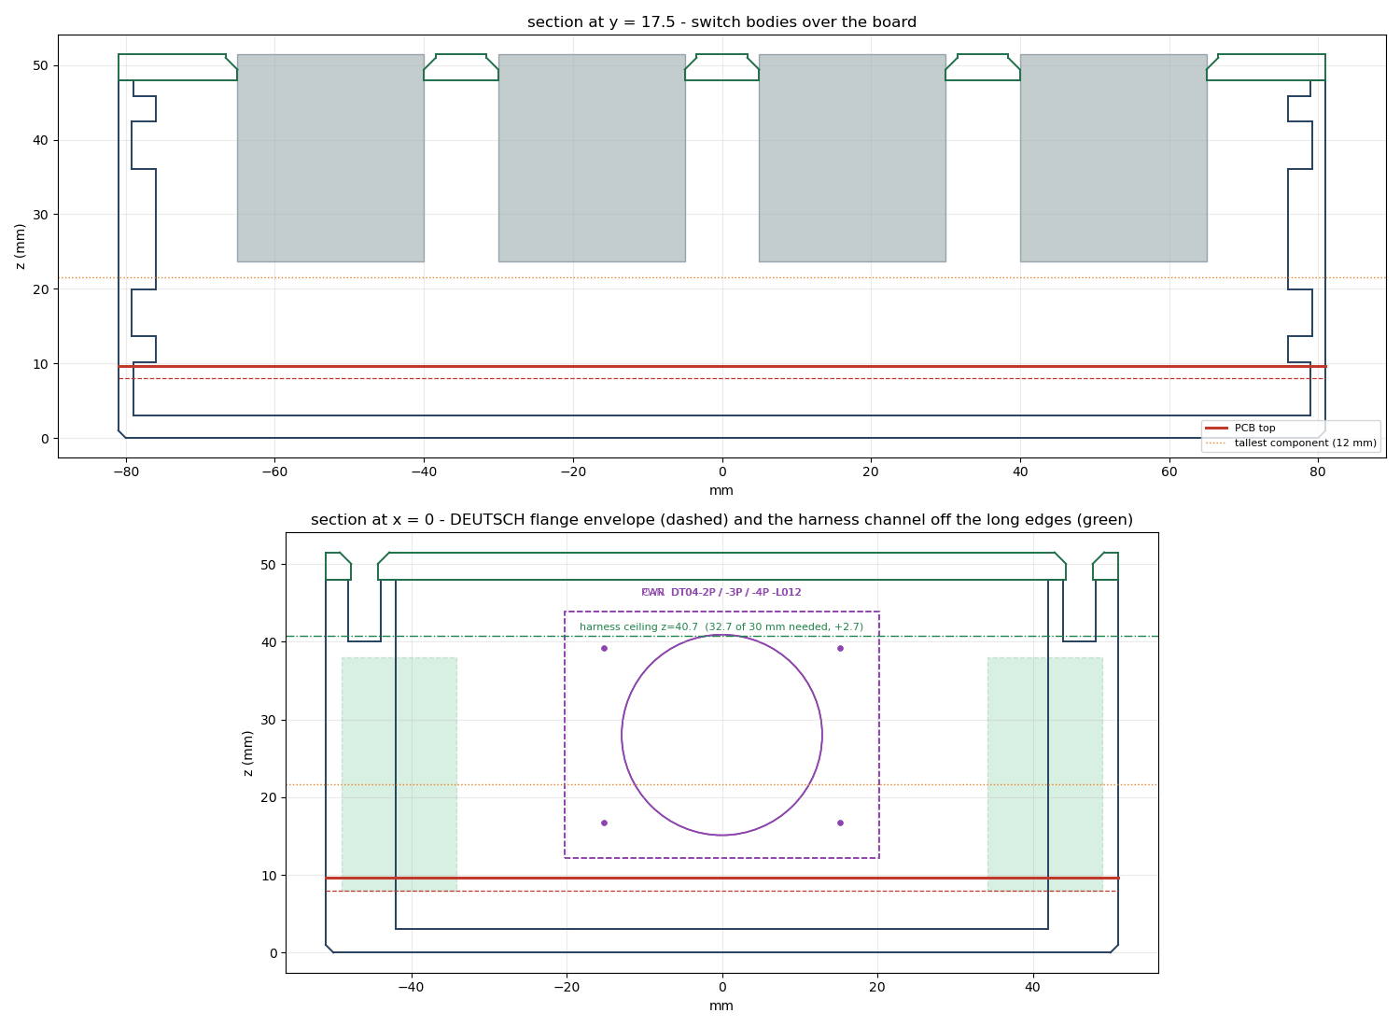
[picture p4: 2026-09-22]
enclosure/images/sections-revA.png

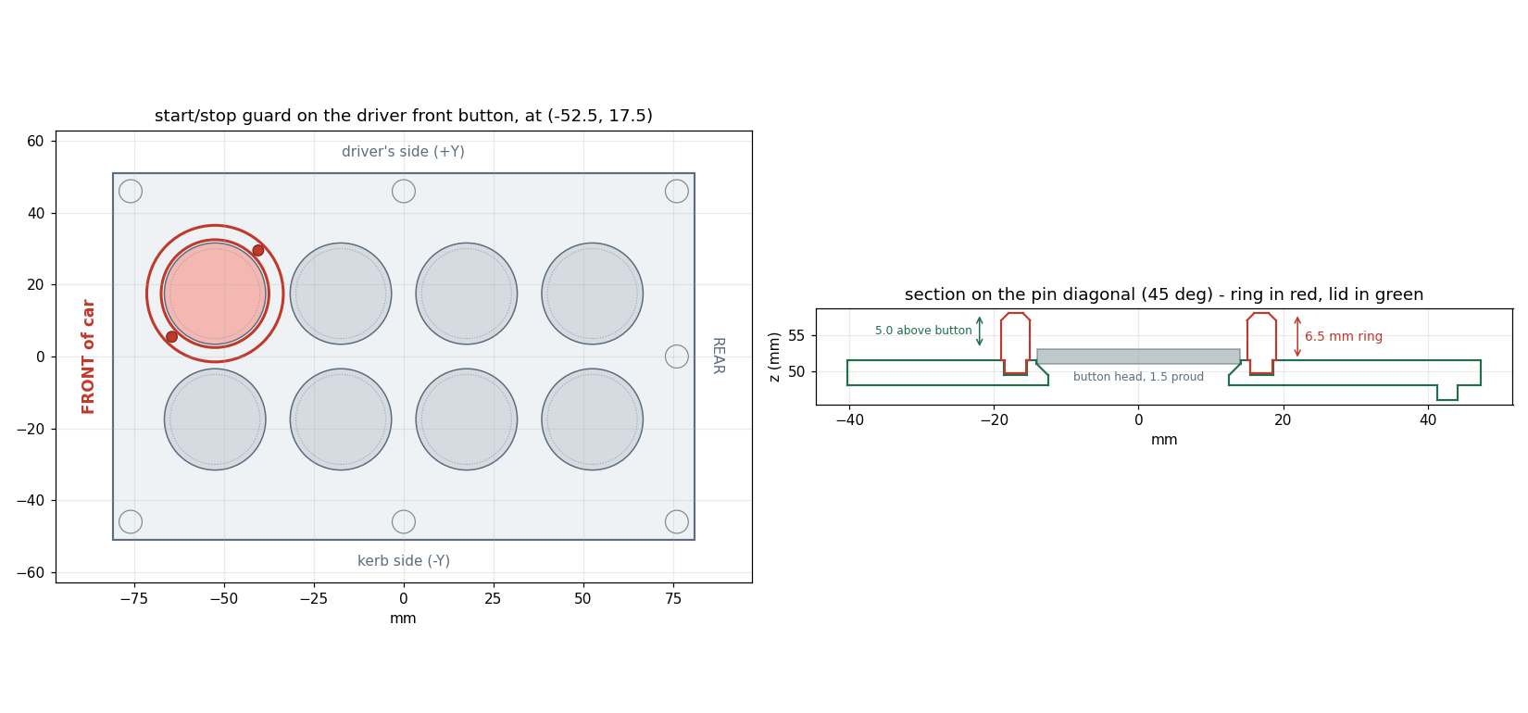
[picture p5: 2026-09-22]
enclosure/images/guard_detail-revB-8way.png

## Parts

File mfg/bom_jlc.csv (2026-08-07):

Comment | Designator | Footprint | LCSC Part #
CL21A106KAYNNNE 25V X5R | C_3V3I,C_5V | C_0805_2012Metric | C15850
CC0805KRX7R9BB104 50V X7R | C_3V3O,C_CAN,C_EEP,C_IMU1,C_IMU2,C_LSW,C_LVS,C_M1,C_M2,C_M3,C_M4,C_M5,C_NRST,C_SI1,C_SI2,C_SI3,C_SO1,C_SO2,C_SO3,C_VDDA | C_0805_2012Metric | C49678
CS3225X7R106K500NRL 50V X7R 1210 | C_BULK | C_1210_3225Metric | C2918502
CL21A475KAQNNNE 25V X5R | C_MB | C_0805_2012Metric | C1779
CL21A225KBQNNNE 50V X5R | C_VCAP | C_0805_2012Metric | C377773
CL21C200JBANNNC 50V C0G | C_Y1A,C_Y1B,C_Y2A,C_Y2B | C_0805_2012Metric | C1798
SS34 3A 40V SMA | D1 | D_SMA | C8678
SMAJ33A 400W SMA | D2 | D_SMA | C353454
SZNUP2105LT1G SOT-23 | D_CAN | SOT-23 | C233494
NCD0805G1 520nm | D_LED1 | LED_0805_2012Metric | C84260
NCD0805R1 | D_LED2 | LED_0805_2012Metric | C84256
1812L050/60GR 500mA hold / 1A trip, 60V | F1 | R_1812_4532Metric | C19078719
2.54-1x6P straight pin | JB2 | WaveshareBuck_OUT_3x3_P2.54mm | C37208
KF2EDGV-3.5-3P header | J_AUX,J_CAN1,J_CAN2 | TerminalBlock_KF2EDG-3.5-3P_1x03_P3.50mm_Horizontal | C441322
PZ254V-11-03P 1x3 2.54mm | J_BOOT | PinHeader_1x03_P2.54mm_Vertical | C2937625
KF2EDGV-3.5-7P header | J_CH1,J_CH2,J_CH3 | TerminalBlock_KF2EDG-3.5-7P_1x07_P3.50mm_Horizontal | C441326
KF2EDGV-3.5-2P header | J_IGN,J_PWR | TerminalBlock_KF2EDG-3.5-2P_1x02_P3.50mm_Horizontal | C441321
PZ254V-11-05P 1x5 2.54mm | J_SWD | PinHeader_1x05_P2.54mm_Vertical | C492404
TYPE-C-31-M-12 16P | J_USB | USB_C_Receptacle_HCTL_HC-TYPE-C-16P-01A | C165948
0805W8F0000T5E | R_ADDR | R_0805_2012Metric | C17477
0805W8F1004T5E 1% | R_AH1,R_AH2,R_AH3,R_IGH,R_SH1,R_SH2,R_SH3,R_SH4,R_SH5,R_SH6,R_SH7,R_SH8,R_SH9,R_SH10,R_SH11,R_SH12,R_SH13,R_SH14,R_SH15,R_SH16,R_SH17,R_SH18,R_SH19,R_SH20,R_SH21 | R_0805_2012Metric | C17514
0805W8F2703T5E 1% | R_AL1,R_AL2,R_AL3,R_IGL,R_SL1,R_SL2,R_SL3,R_SL4,R_SL5,R_SL6,R_SL7,R_SL8,R_SL9,R_SL10,R_SL11,R_SL12,R_SL13,R_SL14,R_SL15,R_SL16,R_SL17,R_SL18,R_SL19,R_SL20,R_SL21 | R_0805_2012Metric | C17589
0805W8F1002T5E 1% | R_BOOT,R_OE,R_PU1,R_PU2,R_PU3,R_PU4,R_PU5,R_PU6,R_PU7,R_PU8,R_PU9,R_PU10,R_PU11,R_PU12,R_PU13,R_PU14,R_PU15,R_PU16,R_PU17,R_PU18,R_PU19,R_PU20,R_PU21,R_RS | R_0805_2012Metric | C17414
0805W8F5101T5E 1% | R_CC1,R_CC2 | R_0805_2012Metric | C27834
0805W8F1001T5E 1% | R_LED1,R_LED2,R_LHOLD | R_0805_2012Metric | C17513
0805W8F470JT5E 1% | R_LG | R_0805_2012Metric | C17714
0805W8F4702T5E 1% | R_LIGN | R_0805_2012Metric | C17713
0805W8F2202T5E 1% | R_LPD | R_0805_2012Metric | C17560
0805W8F4701T5E 1% | R_SCL,R_SDA | R_0805_2012Metric | C17673
0805W8F1200T5E 1% | R_TERM | R_0805_2012Metric | C17437
1.27-8P DIP switch | SW_CFG | SW_DIP_SPSTx08_Slide_KingTek_DSHP08TS_W7.62mm_P1.27mm | C6386921
TL3342F260QG | SW_RST | SW_SPST_TL3342 | C2886894
3.3V CAN transceiver | U_CAN | SOIC-8_3.9x4.9mm_P1.27mm | C12084
TPL7407LAPWR TSSOP-16, 7ch low-side driver | U_DRV1,U_DRV2,U_DRV3 | TSSOP-16_4.4x5mm_P0.65mm | C2149827
SUBSTITUTED: M95640-RMN6TP for the 25LC640 | U_EEP | SOIC-8_3.9x4.9mm_P1.27mm | C283461
Bosch 6-axis IMU | U_IMU | Bosch_LGA-14_3x2.5mm_P0.5mm | C2836813
BTS7040-1EPZ | U_LATCH | Infineon_PG-TSDSO-14-22 | C534838
SUBSTITUTED: AMS1117-3.3 SOT-223 | U_LDO | SOT-223-3_TabPin2 | C6186
LQFP-64 10x10 | U_MCU | LQFP-64_10x10mm_P0.5mm | C69336
SN74HC165DR(LX) | U_SI1,U_SI2,U_SI3 | SOIC-16_3.9x9.9mm_P1.27mm | C22384789
74HC595D,118 Nexperia | U_SO1,U_SO2,U_SO3 | SOIC-16_3.9x9.9mm_P1.27mm | C5947
X50328MSB2GI SMD5032-2P 20pF | Y1 | Crystal_SMD_5032-2Pin_5.0x3.2mm | C115962
Q13FC13500004 SMD3215-2P | Y2 | Crystal_SMD_3215-2Pin_3.2x1.5mm | C32346

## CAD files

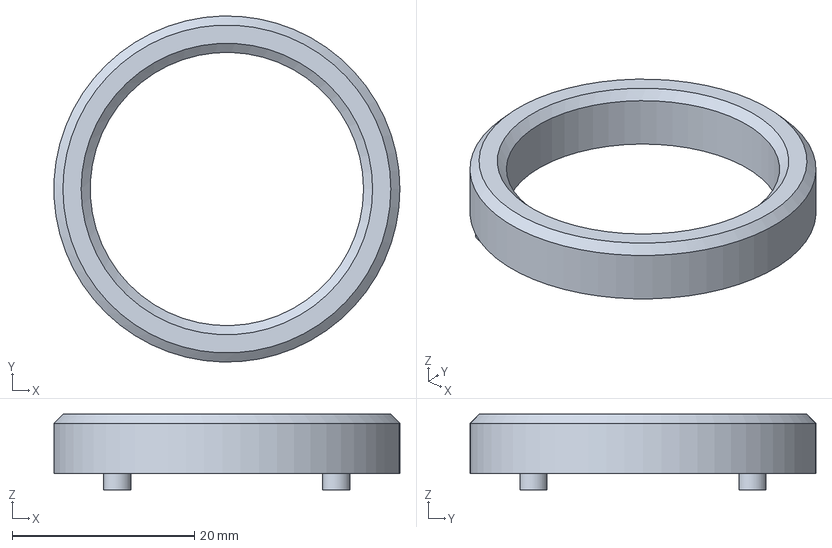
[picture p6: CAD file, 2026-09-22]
enclosure/exports/Guard-Ring-revA.step
38.0 x 38.0 x 8.30 mm

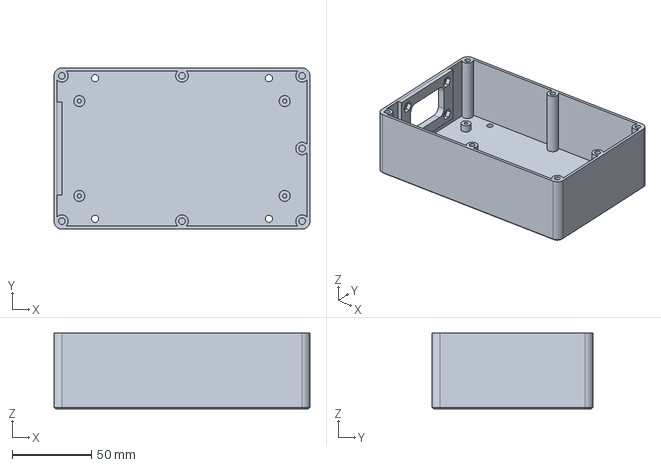
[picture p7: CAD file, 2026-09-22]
enclosure/exports/Enclosure-Box-revB-8way.step
162.0 x 102.0 x 48.0 mm

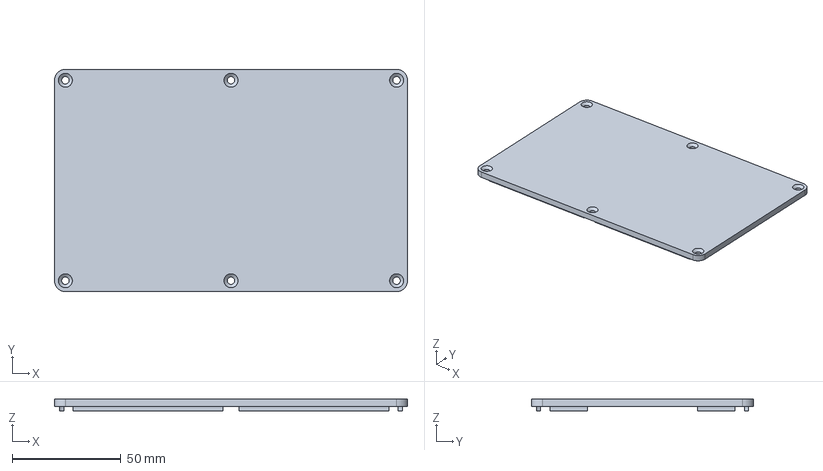
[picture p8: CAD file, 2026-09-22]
enclosure/exports/Lid-Blank-revA.step
162.0 x 102.0 x 5.50 mm

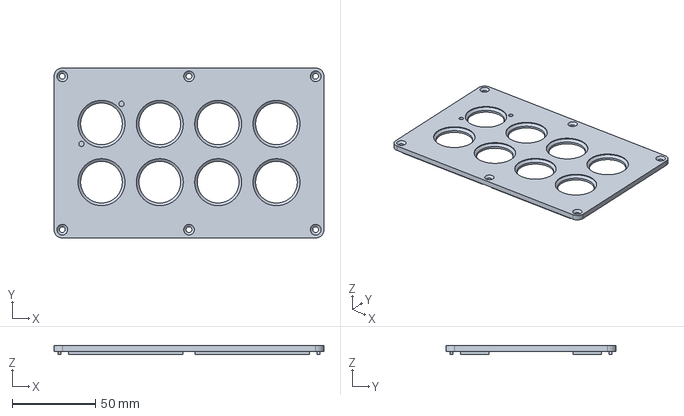
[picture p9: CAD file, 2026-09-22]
enclosure/exports/Lid-Keypad-revA.step
162.0 x 102.0 x 5.50 mm

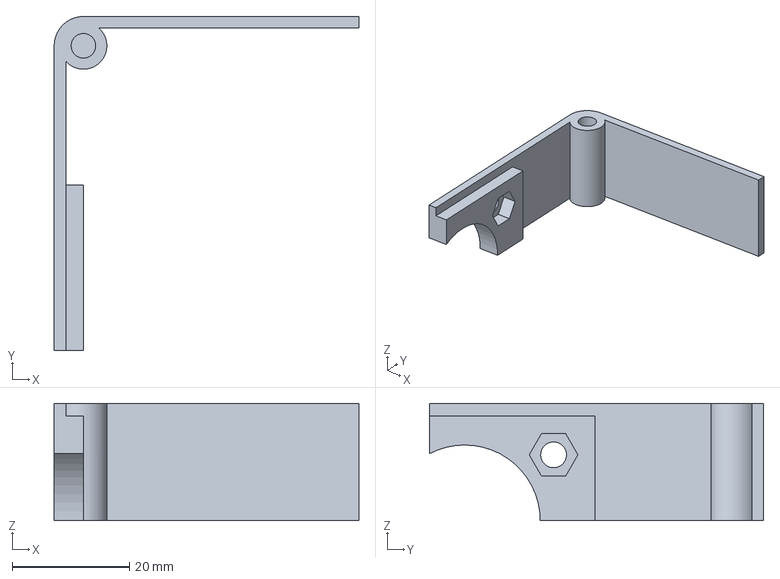
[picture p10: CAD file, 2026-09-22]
enclosure/exports/Corner-Coupon-Box-revA.step
52.0 x 57.0 x 20.0 mm

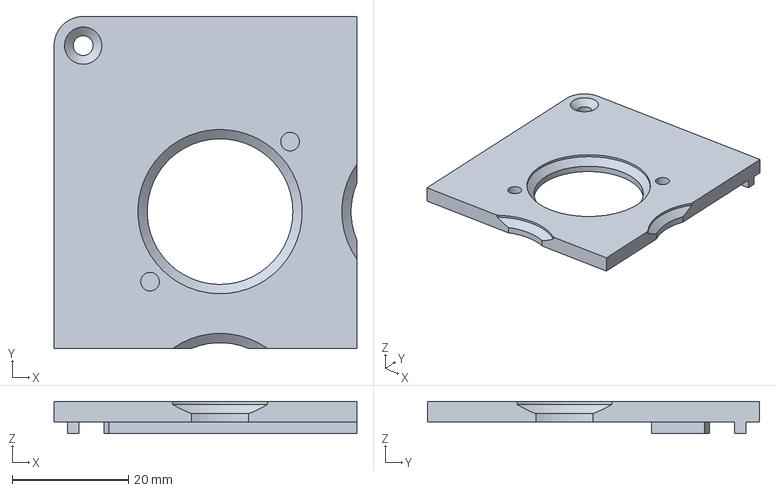
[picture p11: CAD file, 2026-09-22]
enclosure/exports/Corner-Coupon-Lid-revB-8way.step
52.0 x 57.0 x 5.50 mm

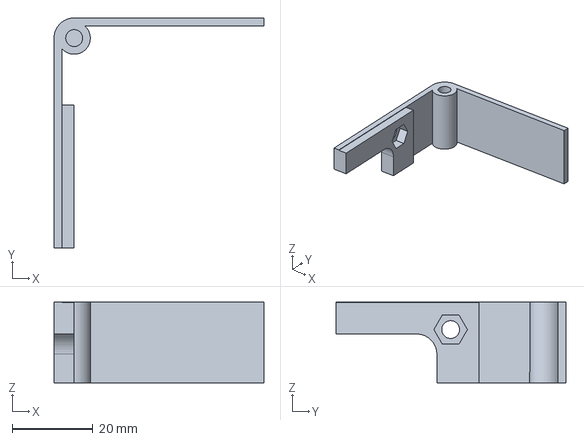
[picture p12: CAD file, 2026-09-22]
enclosure/exports/Corner-Coupon-Box-revB-8way.step
52.0 x 57.0 x 20.0 mm

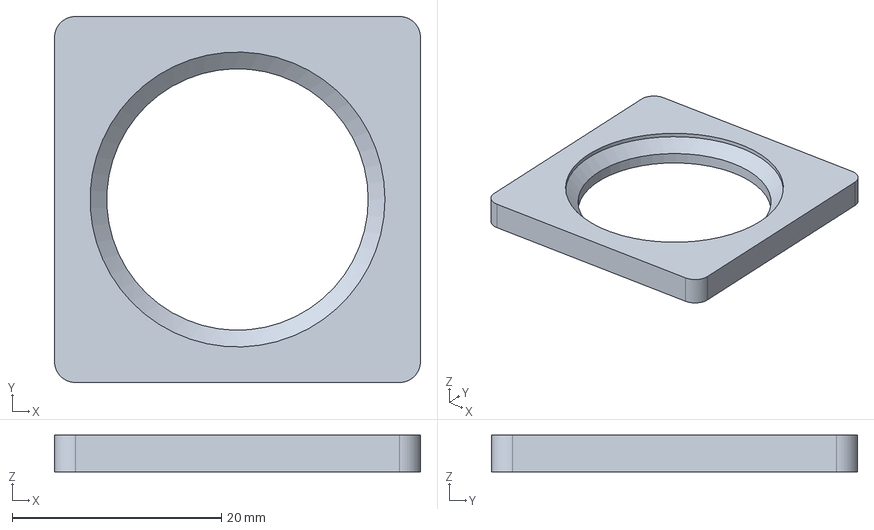
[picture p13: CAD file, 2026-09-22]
enclosure/exports/Test-Coupon.step
35.0 x 35.0 x 3.50 mm

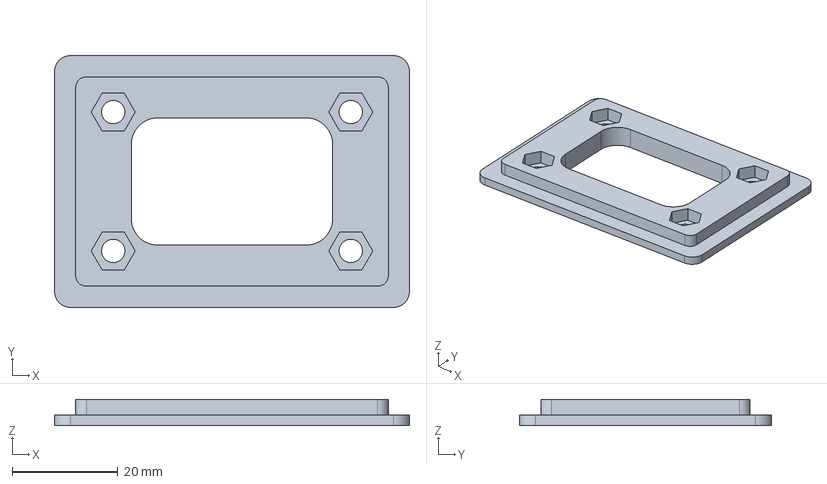
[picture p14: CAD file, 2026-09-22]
enclosure/exports/Port-Coupon-dt-8way-revB-8way.step
67.0 x 47.5 x 5.00 mm

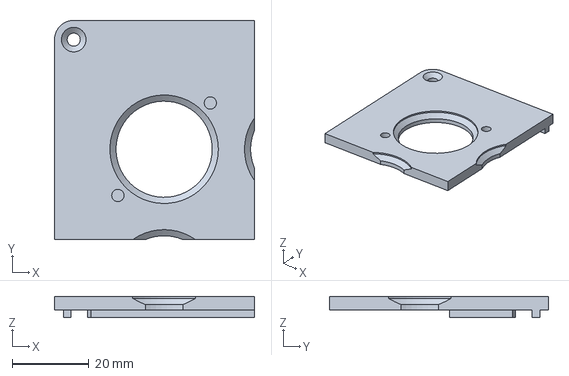
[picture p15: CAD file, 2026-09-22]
enclosure/exports/Corner-Coupon-Lid-revA.step
52.0 x 57.0 x 5.50 mm

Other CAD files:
enclosure/exports/Enclosure-Box-revA.step
enclosure/exports/Guard-Ring-revB-8way.step
enclosure/exports/Lid-Keypad-revB-8way.step
enclosure/exports/Lid-Blank-revB-8way.step
enclosure/Corner-Coupon-Box-revA.FCStd
enclosure/Corner-Coupon-Box-revB-8way.FCStd
enclosure/Corner-Coupon-Lid-revA.FCStd
enclosure/Corner-Coupon-Lid-revB-8way.FCStd
enclosure/Enclosure-Box-revA.FCStd
enclosure/Enclosure-Box-revB-8way.FCStd
enclosure/Guard-Ring-revA.FCStd
enclosure/Guard-Ring-revB-8way.FCStd
enclosure/Lid-Blank-revA.FCStd
enclosure/Lid-Blank-revB-8way.FCStd
enclosure/Lid-Keypad-revA.FCStd
enclosure/Lid-Keypad-revB-8way.FCStd
enclosure/Port-Coupon-dt-8way-revB-8way.FCStd
enclosure/Test-Coupon.FCStd
enclosure/exports/Corner-Coupon-Box-revA.3mf
enclosure/exports/Corner-Coupon-Box-revB-8way.3mf
enclosure/exports/Corner-Coupon-Lid-revA.3mf
enclosure/exports/Corner-Coupon-Lid-revB-8way.3mf
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

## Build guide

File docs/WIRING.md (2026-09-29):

# Wiring an Exocet with two RCM boards

Road-registered, all-LED lighting, **sealed rear clusters with a shared ground per
cluster**. Those three facts decide almost everything below, so re-read this section
before changing anything.

## The constraint that decides the architecture

**Every channel is low-side.** The load takes a permanent +12V feed and the board sinks
its ground. Two consequences, and they are not firmware-fixable:

1. **Anything driven directly needs its ground routed back to the board.** That is an
   extra thin wire per function, into the cabin.
2. **A shared-ground cluster cannot be switched per function.** Breaking the shared
   ground kills tail, indicator and brake together. The only way to switch those
   individually is high-side — a relay, or a solid-state high-side switch.

The second point is why this car's rear lighting still needs relays. It is a property of
the lamps, not of the board.

**The board is also a 600 mA device in the cabin.** It drives coils, not loads. Anything
above roughly half an amp stays a relay out at the fuse panel rather than dragging heavy
cable in and back out again.

## Relay count

| Circuit | Why it must be a relay |
|---|---|
| Main (ECU feed, injectors, coils) | current |
| Fuel pump | current |
| Fan | current |
| Starter | current; driven by the ECU, not this board |
| Headlight low | current |
| Headlight high | current |
| Horn | current |
| Tail / park | shared cluster ground — high-side only |

**Eight.** Add a ninth for a rear fog if one is fitted.

### Who drives which coil

**The ECU owns main, starter and fuel pump.** rusEFI has the sensor data those three
depend on and does not need a bus to act, so they are wired to its outputs directly.
The relay module drives the remaining five: fan, tail, both headlight circuits and the
horn.

The consequence is worth stating plainly: **fuelling and ignition do not depend on this
board's outputs, or on CAN, at all.** The relay module decides whether the car is on. It
has no say in whether the engine keeps running once it is.

### Telling the ECU the ignition is on

With a momentary start button there is no key-on wire, so something has to give the ECU a
steady "ignition on". **Feed it from `+12V_SW`, not from a channel.**

A channel is the obvious choice and it is the wrong one. Every channel goes
high-impedance on any reset and comes back about 22 ms later, and an ECU reading that as
key-off mid-drive is exactly the failure this architecture exists to avoid. `+12V_SW` is
the BTS7040's output rather than a shift-register output, and it does not drop: a reset
was measured on revA with the ignition released and the board came straight back, because
the rail capacitance bridges the few milliseconds before firmware re-asserts
`LATCH_HOLD`.

It needs no fuse. The rail comes off the BTS7040, a smart high-side switch, so it is
already e-fused -- current limit, short-circuit survival and thermal shutdown are in the
part. The budget is the switch's **4.5 A**, less the board's own draw, and today that
rail feeds nothing but the buck.

### VIGN is a power input, and it is diode-isolated

Checked against the **super-uaEFI rev b schematic**, power sheet (`Module-power_12and5V`).

`IN_VIGN` (the vehicle pin) goes through **D417, a B5819W Schottky**, onto the same
internal rail that `V12_RAW` reaches through **D416**, another B5819W. That rail runs
into the input filter and then straight into the **LMR14020 buck**. So the two supplies
are **diode-OR'd into the ECU's main converter**: key-on power really can run the whole
ECU, which matches rusEFI's general wiring guidance.

Two consequences, and they point in opposite directions:

**Size it as a supply, not a signal.** Worst case is the buck's whole draw -- order of an
amp, less whenever the permanent feed is also present and sharing. This is not a pin to
hang off `JB1`'s 0.1 inch header; it wants the `+12V_SW` terminal revision B should add.

**Nothing can flow back out of it.** D417's cathode is on the internal rail and its anode
on the pin, so current enters the ECU and cannot leave. **No blocking diode is needed in
the feed from `+12V_SW`** -- the ECU already has one, and a second would only cost another
few hundred millivolts.

The voltage the ECU *reads* is a separate path: `IN_VIGN` also feeds an R411 33k / R413
6.8k divider with a 100n cap and 1N4148 clamps to `VBAT`, and that node -- confusingly
also called `VIGN` -- is the ADC input on **PA5**. On its own that divider plus the
indicator LED draws well under a milliamp; the current that matters is the buck's.

Worth noting for anyone reading rusEFI's guide and worrying about the main relay feeding
back into VIGN: on this board `+12V_FROM_MAIN_RELAY` and `+12V_FROM_KEY` are separate
nets, bridged only by **R9, which is marked DNP**. They are not joined unless somebody
fits that resistor.

Schematic revisions differ -- the same repository carries v5 and v9 mechanical files -- so
re-check against the revision actually in the car before relying on this.

Because the ECU owns the fuel pump, there is no reason to set a `failsafe_state` bit for
priming — the ECU primes on its own ignition input.

Two that look like they need one and do not:

- **Reverse light** — the gearbox switch already switches +12V. Leave it hardwired. The
  board gains nothing by being in that circuit.
- **Brake lights** — hardwired, deliberately. A mechanical switch is simpler and more
  reliable than anything running on a microcontroller, and there is no upside to
  inserting one. Tap the switched feed into a spare input if the board should *know*
  about the brake (the ignition state machine needs this), but keep it out of the lamp
  circuit.

### Indicators and hazards: keep the flasher

Use a conventional flasher can, indicator stalk and hazard switch, entirely outside both
boards. Three reasons:

1. **The clusters are shared-ground**, so the board would need a relay per side anyway.
2. **A relay flashed continuously wears out.** At roughly 1.5 Hz, an hour on hazards is
   about 5000 operations. Relays are rated in the hundreds of thousands of cycles, so it
   is not immediate — but it is pointless wear for no gain.
3. The same argument as the brake lights: it already works, standalone, without power,
   firmware or a bus.

**This is a real loss.** `OUT_FLASH` exists precisely so several channels flash on one
shared period and stay in phase, which is what makes hazards look right instead of like
two indicators that happen to be on. With separately-grounded LED clusters, that feature
would have removed the flasher can *and* both relays, and given per-channel open-circuit
detection instead of bulb-failure fast-flash. Sealed clusters cost you all of that.

If a future set of rear lamps can be grounded per function, revisit this.

## What can be driven directly

Only loads with their own ground, under ~600 mA:

- rain light, if it is a separate unit rather than part of a cluster
- shift light, warning buzzers
- boost solenoid, line lock
- anything you add later with a dedicated earth

Everything with a shared ground is a relay, whatever its current.

## Channel budget

**Relay module** (node 0-3, channels default to outputs):

| Ch | Function | Notes |
|---|---|---|
| 1 | `FN_FAN_1` | relay |
| 2 | `FN_TAIL` | relay — shared cluster ground |
| 3 | `FN_HEADLIGHT_LOW` | relay |
| 4 | `FN_HEADLIGHT_HIGH` | relay |
| 5 | `FN_HORN` | relay; `OUT_PULSE` if you want a chirp |
| 6 | `FN_RAIN_LIGHT` | direct, if it is a separate unit with its own earth |
| 7-9 | spare outputs | |
| 10 | `FN_IN_BRAKE` (input) | from the hardwired brake switch |
| 11 | spare input | |

Eleven of twenty-one, with plenty in hand. Main, starter and fuel pump are absent because
the ECU drives them. The starter would be absent regardless: the firmware masks it out of
every CAN and peer path so a stray or replayed frame cannot crank the engine.

**Keypad** (node 4-7): ten buttons and their lamps, alternating input/output -- see "The
keypad board" above. Headlights, high beam, horn, rain light, fan override, pump prime,
traction/launch/map-select, start/stop.

Buttons switch **+12V into the channel** — inputs sense high, and need more than 10.87 V
at the terminal to read as pressed.

## Two buttons: ignition, and start/stop

With buttons to spare, split the two jobs rather than overloading one.

| Button | Goes to | Does |
|---|---|---|
| **Ignition** | `J_IGN` on the relay module | press to wake, hold to shut the car down |
| **Start/stop** | a keypad channel, bound to the ECU's start/stop command | cranks, and stops a running engine |

**Start/stop goes to the ECU over CAN.** The button is an ordinary keypad channel bound in
`ecu_cmd[]` (see "Asking the ECU to do things" below). Each press sends
`ECU_CAN_BUS_USER_CONTROL`, **extended id `0x77000C`** -- the same frame uaDASH's on-screen
start button sends -- which lands on rusEFI's `startStopButtonToggle()`, the same entry
point as a physical start button. So this board only asks; the ECU decides. rusEFI owns
`starterControlPin` and `startCrankingDuration`, has RPM off the crank sensor rather than
through a divider that goes unreadable during a crank, and applies its own interlocks. No
start/stop input pin on the ECU is used.

### What splitting them buys

**The brake dependency leaves this board completely.** `ign_brake_ch` stays
`IGN_CH_NONE`, and the whole "the brake decides what this press means" branch becomes
dead code for this install -- the ignition button can no longer be mistaken for a start
attempt, because starting is not its job. The interlock still exists, in the ECU, where
the RPM signal actually is.

Ignition and start become independent: killing ignition cannot be misread as a start, and
a start press cannot end in a shutdown.

The sequence is then exactly a modern car:

1. press **ignition** -- relay module latches, `+12V_SW` comes up, ECU boots
2. press **start/stop** -- ECU cranks, on its own timeout and interlocks
3. press **start/stop** again -- ECU stops the engine; the board stays awake
4. hold **ignition** -- board powers down, `+12V_SW` drops, ECU goes with it

## Asking the ECU to do things

Any input channel can be bound to a TunerStudio command, sent to the ECU as an extended
frame. Six slots:

    rcm_bench ctl ecucmd 0 5 startstop     # ch5 press: crank if stopped, stop if running
    rcm_bench ctl ecucmd 1 7 lua1          # ch7 press: bump rusEFI Lua counter 1
    rcm_bench ctl ecucmd 2 8 stopengine    # ch8 press: unconditional stop
    rcm_bench ctl ecucmd 3 9 22 43         # or any raw subsystem and index
    rcm_bench ctl ecucmd 0 none            # clear a slot

**`lua1`..`lua4` are the interesting ones for a car.** rusEFI has no fixed command for
traction control, launch control or a map switch -- what it has is four counters that a
Lua script can watch. Bind a button to one, write the behaviour in Lua, and none of it
needs a firmware change here.

Stored as a raw (subsystem, index) pair rather than a list of named commands, because
every TunerStudio command is that shape. Adding one is a config change, not a release.

Verified on revA: a touch of +12 V to a bound channel put
`T 0077000C 8 6600140009000000` on the wire -- a `T` record, so genuinely extended --
once per press, with real switch bounce.

### One button or two

`ign_ecu_flags` decides whether the IGNITION button also talks to the ECU. **Both bits
default off, which is the two-button car** -- the ignition button only powers the board,
and a separate button in `ecu_cmd[]` starts the engine. That is the simpler thing to
reason about and the recommended arrangement.

Set both bits for the one-button VW arrangement:

| Gesture | Result |
|---|---|
| single press from off | wakes the board, nothing else |
| wake press **held** with the brake down | wakes the board, then asks the ECU to start |
| press with the brake down, engine off | asks the ECU to start |
| press with the brake **up** | shuts the car down |
| **hold** while running | asks the ECU to stop, then powers down after `ign_shutdown_ms` |

A short press while running does nothing on purpose: stopping takes a deliberate hold, so
a hand catching the dash cannot cut the engine. `ign_hold_stop_ms` defaults to 1000 ms.

Two details that matter when setting this up:

- **The stop gesture sends `TS_STOP_ENGINE`, not the start/stop toggle.** The toggle is
  gated on the ECU's own view of engine speed; a stop must not be. The power-down runs on
  its own timer either way, so a shutdown proceeds identically if the ECU never answers.
- **Set rusEFI's `startButtonSuppressOnStartUpMs` shorter than `ign_wake_start_ms`**
  (2000 ms). rusEFI ignores start requests for a period after it gets ignition power, and
  its own source says that exists for exactly this arrangement -- a start button combined
  with an ECU power-source button. Leave it long and the wake-and-start gesture lands
  while the ECU is still ignoring requests.

## The three `J_AUX` inputs

`J_AUX` gives three more 12 V inputs without spending a channel -- they use the spare
eighth bit of each tile's 74HC165. Debounced like any input, published as byte 3 of the
INPUTS frame, shown on the `s` line of the console as `aux`.

**Input only**, and there is no ground pole on the connector: the return is via `J_PWR`.

They suit switches the board should KNOW about but must not control -- the hardwired
brake feed, a clutch, handbrake or reverse switch. That is what keeps the brake lights on
a mechanical switch while the ignition state machine still sees the pedal.

Like every input here they are **active-high**: the switch feeds +12 V, and above 10.87 V
at the terminal reads as pressed. The one thing to add is a **10 k pull-down from each
used pin to ground**. Channels have one fitted; `J_AUX` does not, so an open switch is
held down only through the 1.27 M divider. Fine at DC, but a high source impedance for a
long run near ignition coils.

## Ground budget

Every channel's return, coil and direct load alike, comes back through **one 3.5 mm pole
on `J_PWR`** rated about 8 A. Eight 80 Ω coils at 14.4 V is 8 x 180 mA = **1.44 A**, so
there is plenty of margin here — but it is the first thing to check before adding
directly-driven loads, and it is the known limit a revision should fix with a second
ground pole.

## The keypad board: buttons AND their LEDs

A keypad is **not** 21 inputs. Each button has an LED in it, and that LED has to be
switched, so the channels alternate:

| Channel | | |
|---|---|---|
| 1 | input | button 1 |
| 2 | output | button 1's LED |
| 3 | input | button 2 |
| 4 | output | button 2's LED |
| … | | |

This car's keypad is **8 buttons**, so 16 channels with 5 spare. 21 channels tops out at
ten buttons, and the firmware's 12 follow slots are sized for that. Two things
follow that are worth knowing before wiring one.

**The role strap's default is wrong for this.** Closing the role DIP makes every channel
default to an input, which suits a pure input panel and not a real keypad. It is only a
default -- set the even channels back to outputs with `ctl chmode` -- but a fresh keypad
does not come up ready to light anything.

**LED current is low-side, like everything else.** The LED's positive side takes a
permanent feed and the channel sinks it. In a moulded button where the lamp shares a
common with the switch, that may not be possible without opening the button up -- the same
constraint the rear light clusters have.

### What the LED should show

The useful thing for a lamp to show is **whether the load is actually on**, not whether
the button was pressed. Those differ exactly when it matters: a blown fuse, a relay that
did not pull in, a channel the relay module refused because it was in failsafe.

**That is not built.** Peer mirroring runs one way -- a relay module follows a keypad's
INPUTS frame -- and it is strictly channel-for-channel. For a lamp to track a load it
would need the reverse: the keypad following the relay module's OUTPUTS frame, and with a
mapping, since keypad channel 2 lights for relay module channel N rather than channel 2.

The pieces are all there. `ecu_follow` already binds a channel to an arbitrary (frame,
bit) pair and this board's own OUTPUTS frame is just another frame on the bus, so a keypad
could follow a relay module today by pointing follow slots at the relay module's broadcast
-- it simply has not been tried, and there are only six slots against ten lamps.

Until then a lamp can mirror the button locally, which is honest about the button and
silent about the load.

## Pairing the two boards

    rcm_bench ctl peer 4 1,2,5 5     # follow node 4 on channels 1,2,5; ch5 latches
    rcm_bench ctl peer none 0        # disable mirroring
    rcm_bench ctl save               # keep it across a power cycle

`RCM_OP_SET_PEER` (0x18) sets the node and both masks and installs the receive filter
for the peer's INPUTS frame. Verified on hardware with a PC impersonating a keypad, so
**a second board is not needed to test this** -- a keypad is only a node broadcasting an
INPUTS frame at `base + node * 0x10 + 1`, which anything on the bus can fake.

**Mirroring is strictly channel-for-channel.** Keypad channel N drives relay module
channel N, so the two channel maps have to be planned together and one button cannot
drive two outputs. That is the other reason the hazard switch stays conventional:
`FN_IN_HAZARD` is a label with no logic behind it.

Two things to know when watching this on a bus:

- **The board's transmit queue runs a couple of broadcast cycles deep**, so the first
  OUTPUTS frame after a command can still predate it. Flushing the host's receive buffer
  is not enough. Settle for a few hundred ms, or read for a while and take the last
  frame, before believing what a channel is doing.
- **Peer frames count as traffic addressed to this board**, so a mirrored channel is not
  reverted by the CAN timeout. Stop the keypad talking entirely and `failsafe_state`
  takes over as usual.

## Historical: peer mirroring was not configurable

The keypad-to-relay-module path is `peer_node`, `peer_mask` and `peer_toggle_mask` —
`peer_toggle_mask` being the one that turns a momentary button into a latching load.
All three are **read by the firmware and written by nothing**. There is no CAN opcode,
so a two-board setup currently needs a recompile to configure.

This is the same gap `ecu_rpm_can_id` had before `RCM_OP_SET_RUN_SRC`, and it needs the
same fix. Note that changing `peer_node` also changes a receive filter, so whatever sets
it must reinstall the filter set — see `install_filters()`.

**Peer mirroring is strictly channel-for-channel.** Keypad channel N drives relay module
channel N, so the two channel maps have to be planned together, and one button cannot
drive two outputs. That is the other reason the hazard switch stays conventional:
`FN_IN_HAZARD` is a label with no logic behind it.

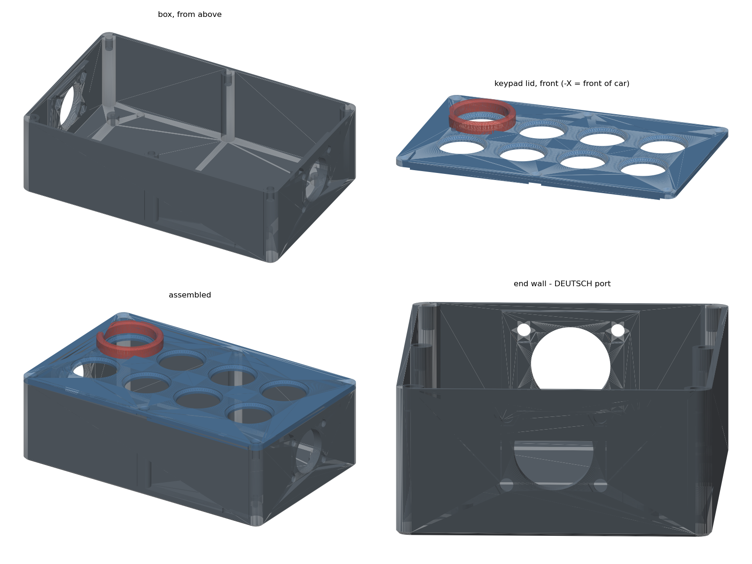
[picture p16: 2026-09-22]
enclosure/images/assembly-revA.png

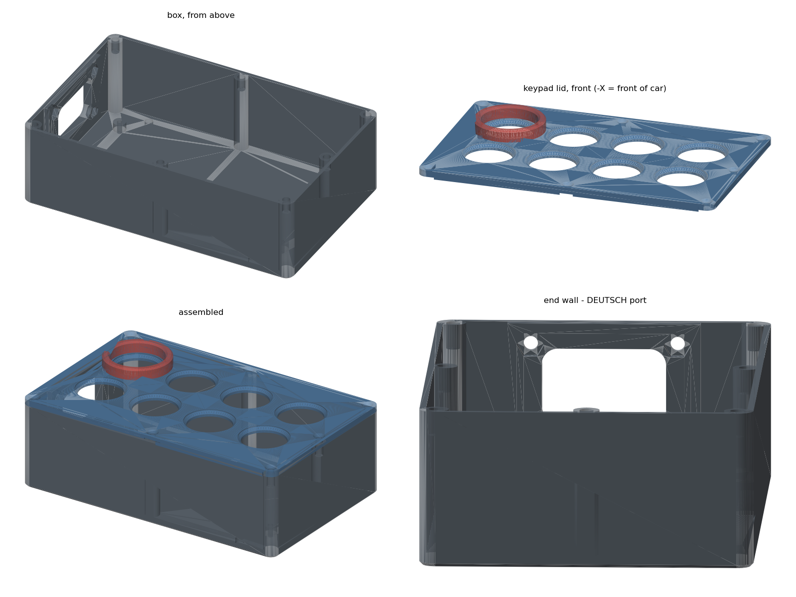
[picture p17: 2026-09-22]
enclosure/images/assembly-revB-8way.png

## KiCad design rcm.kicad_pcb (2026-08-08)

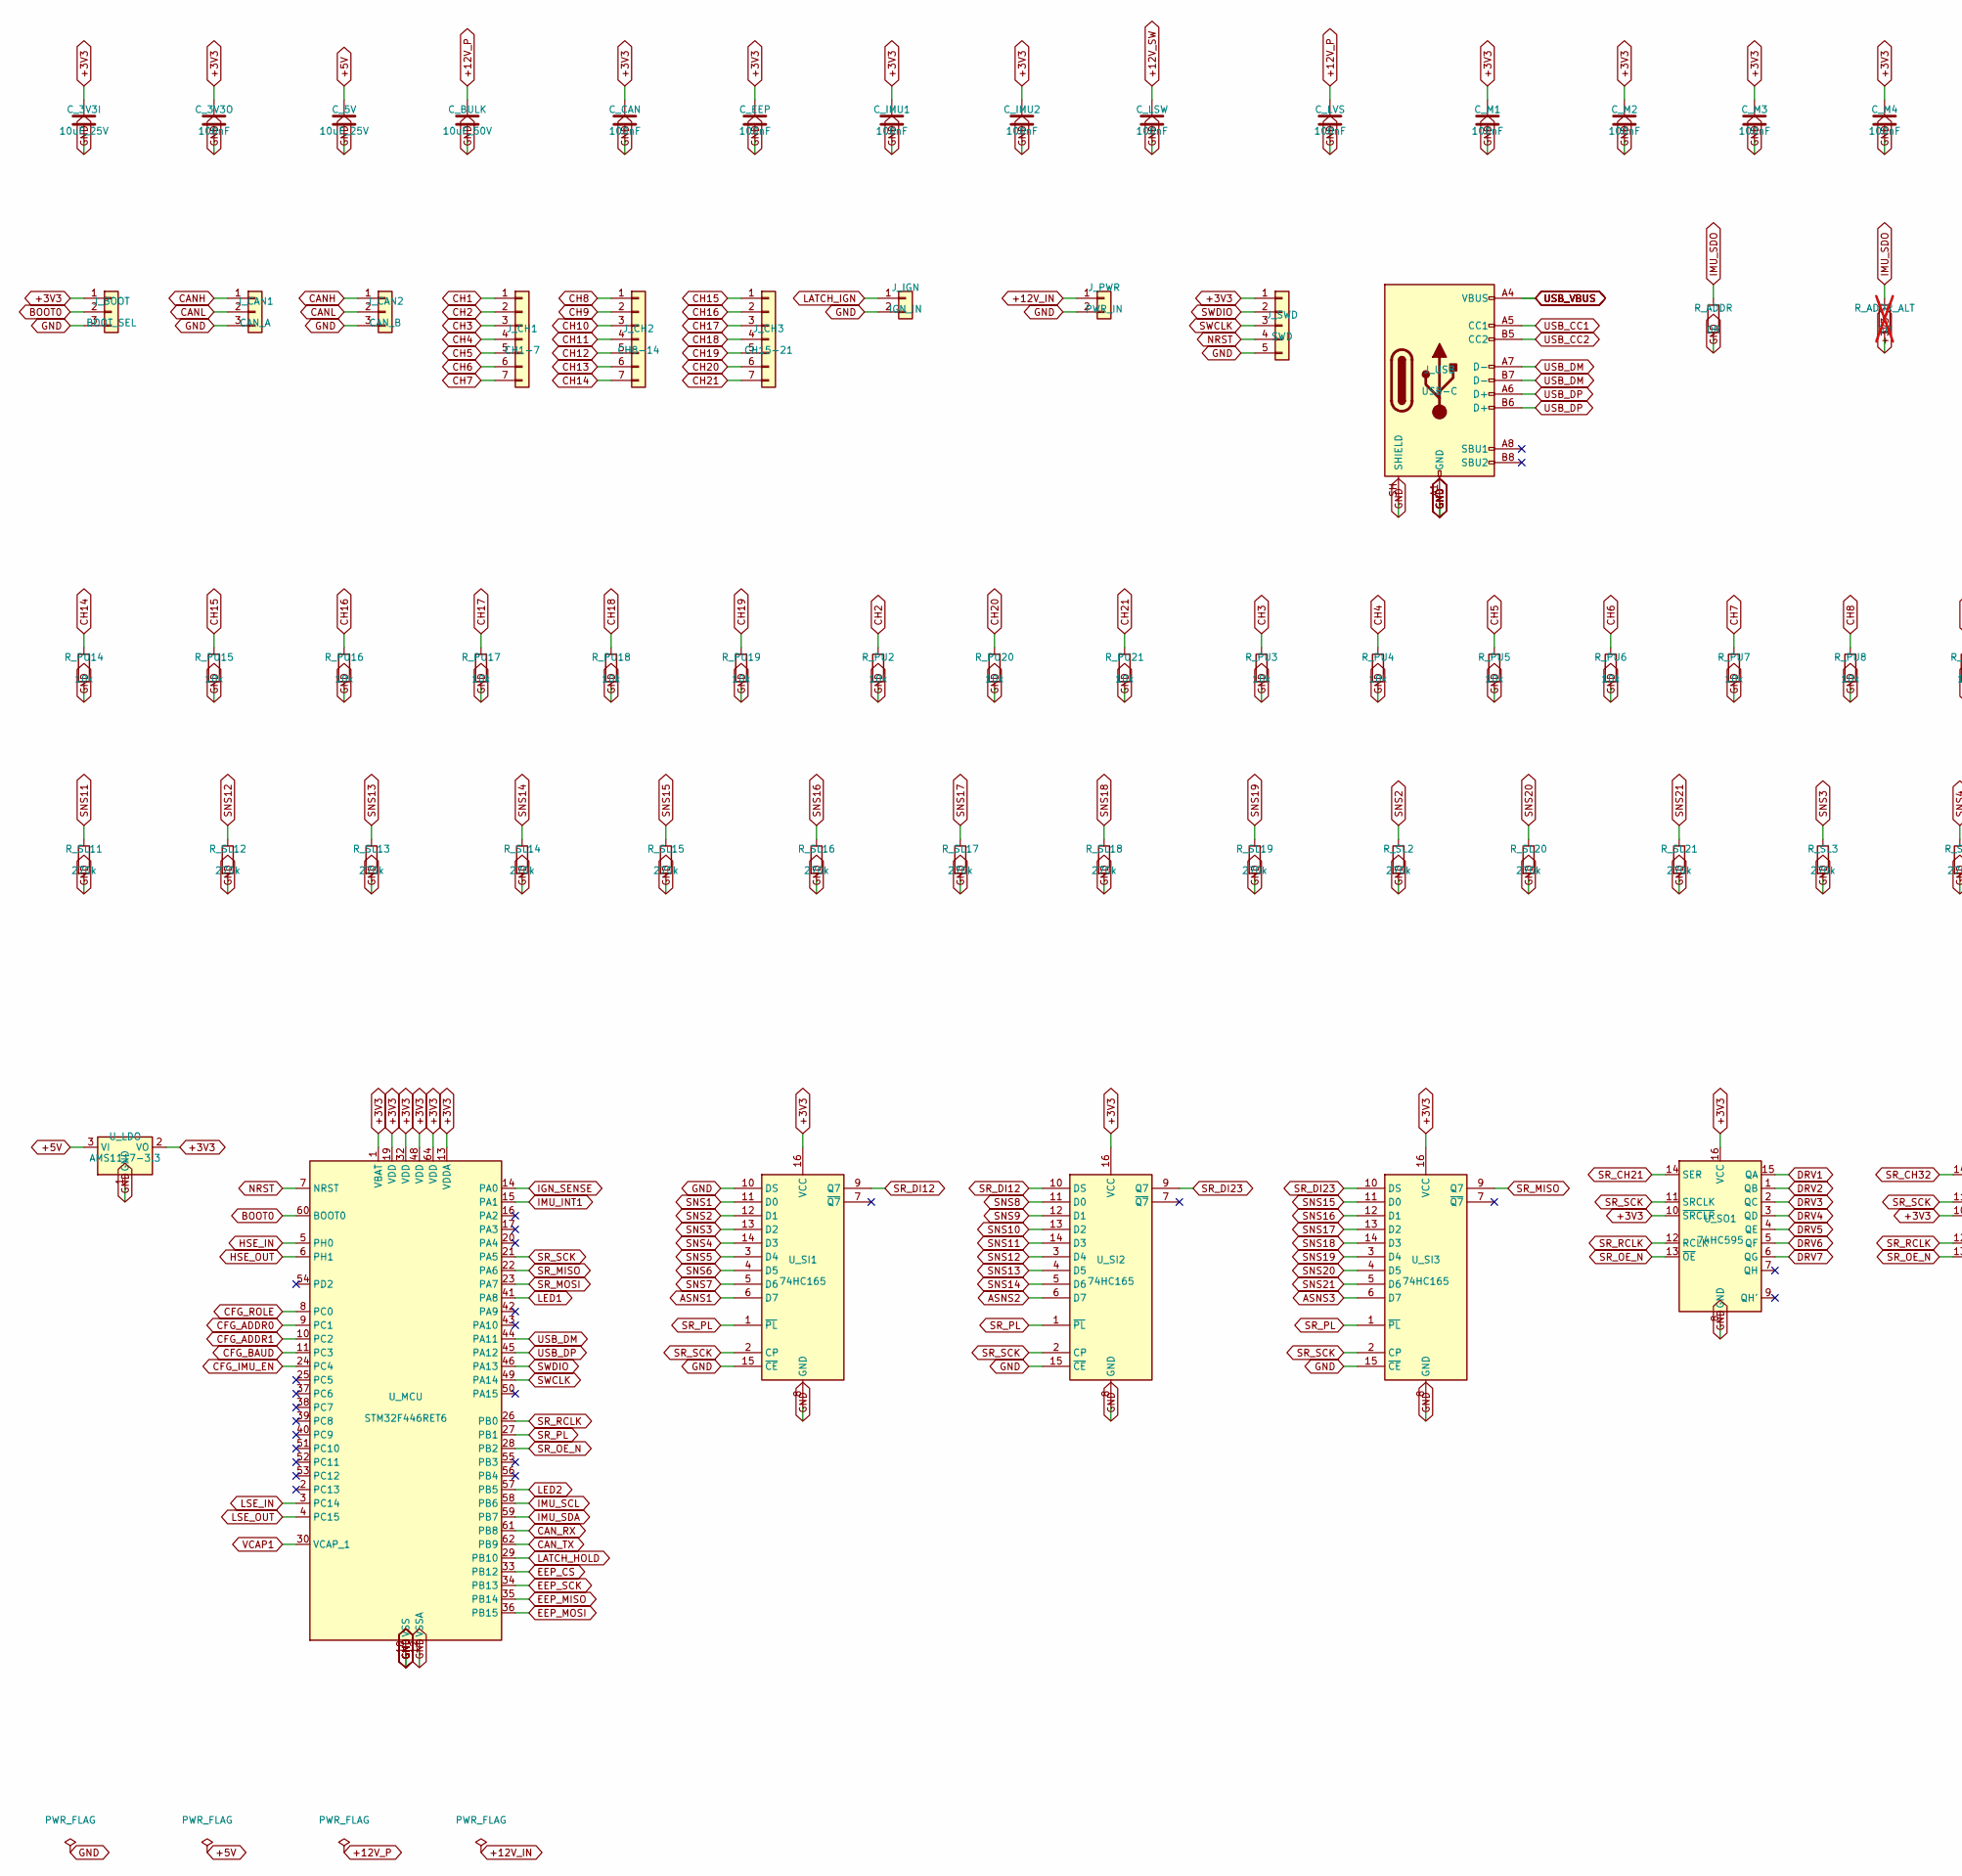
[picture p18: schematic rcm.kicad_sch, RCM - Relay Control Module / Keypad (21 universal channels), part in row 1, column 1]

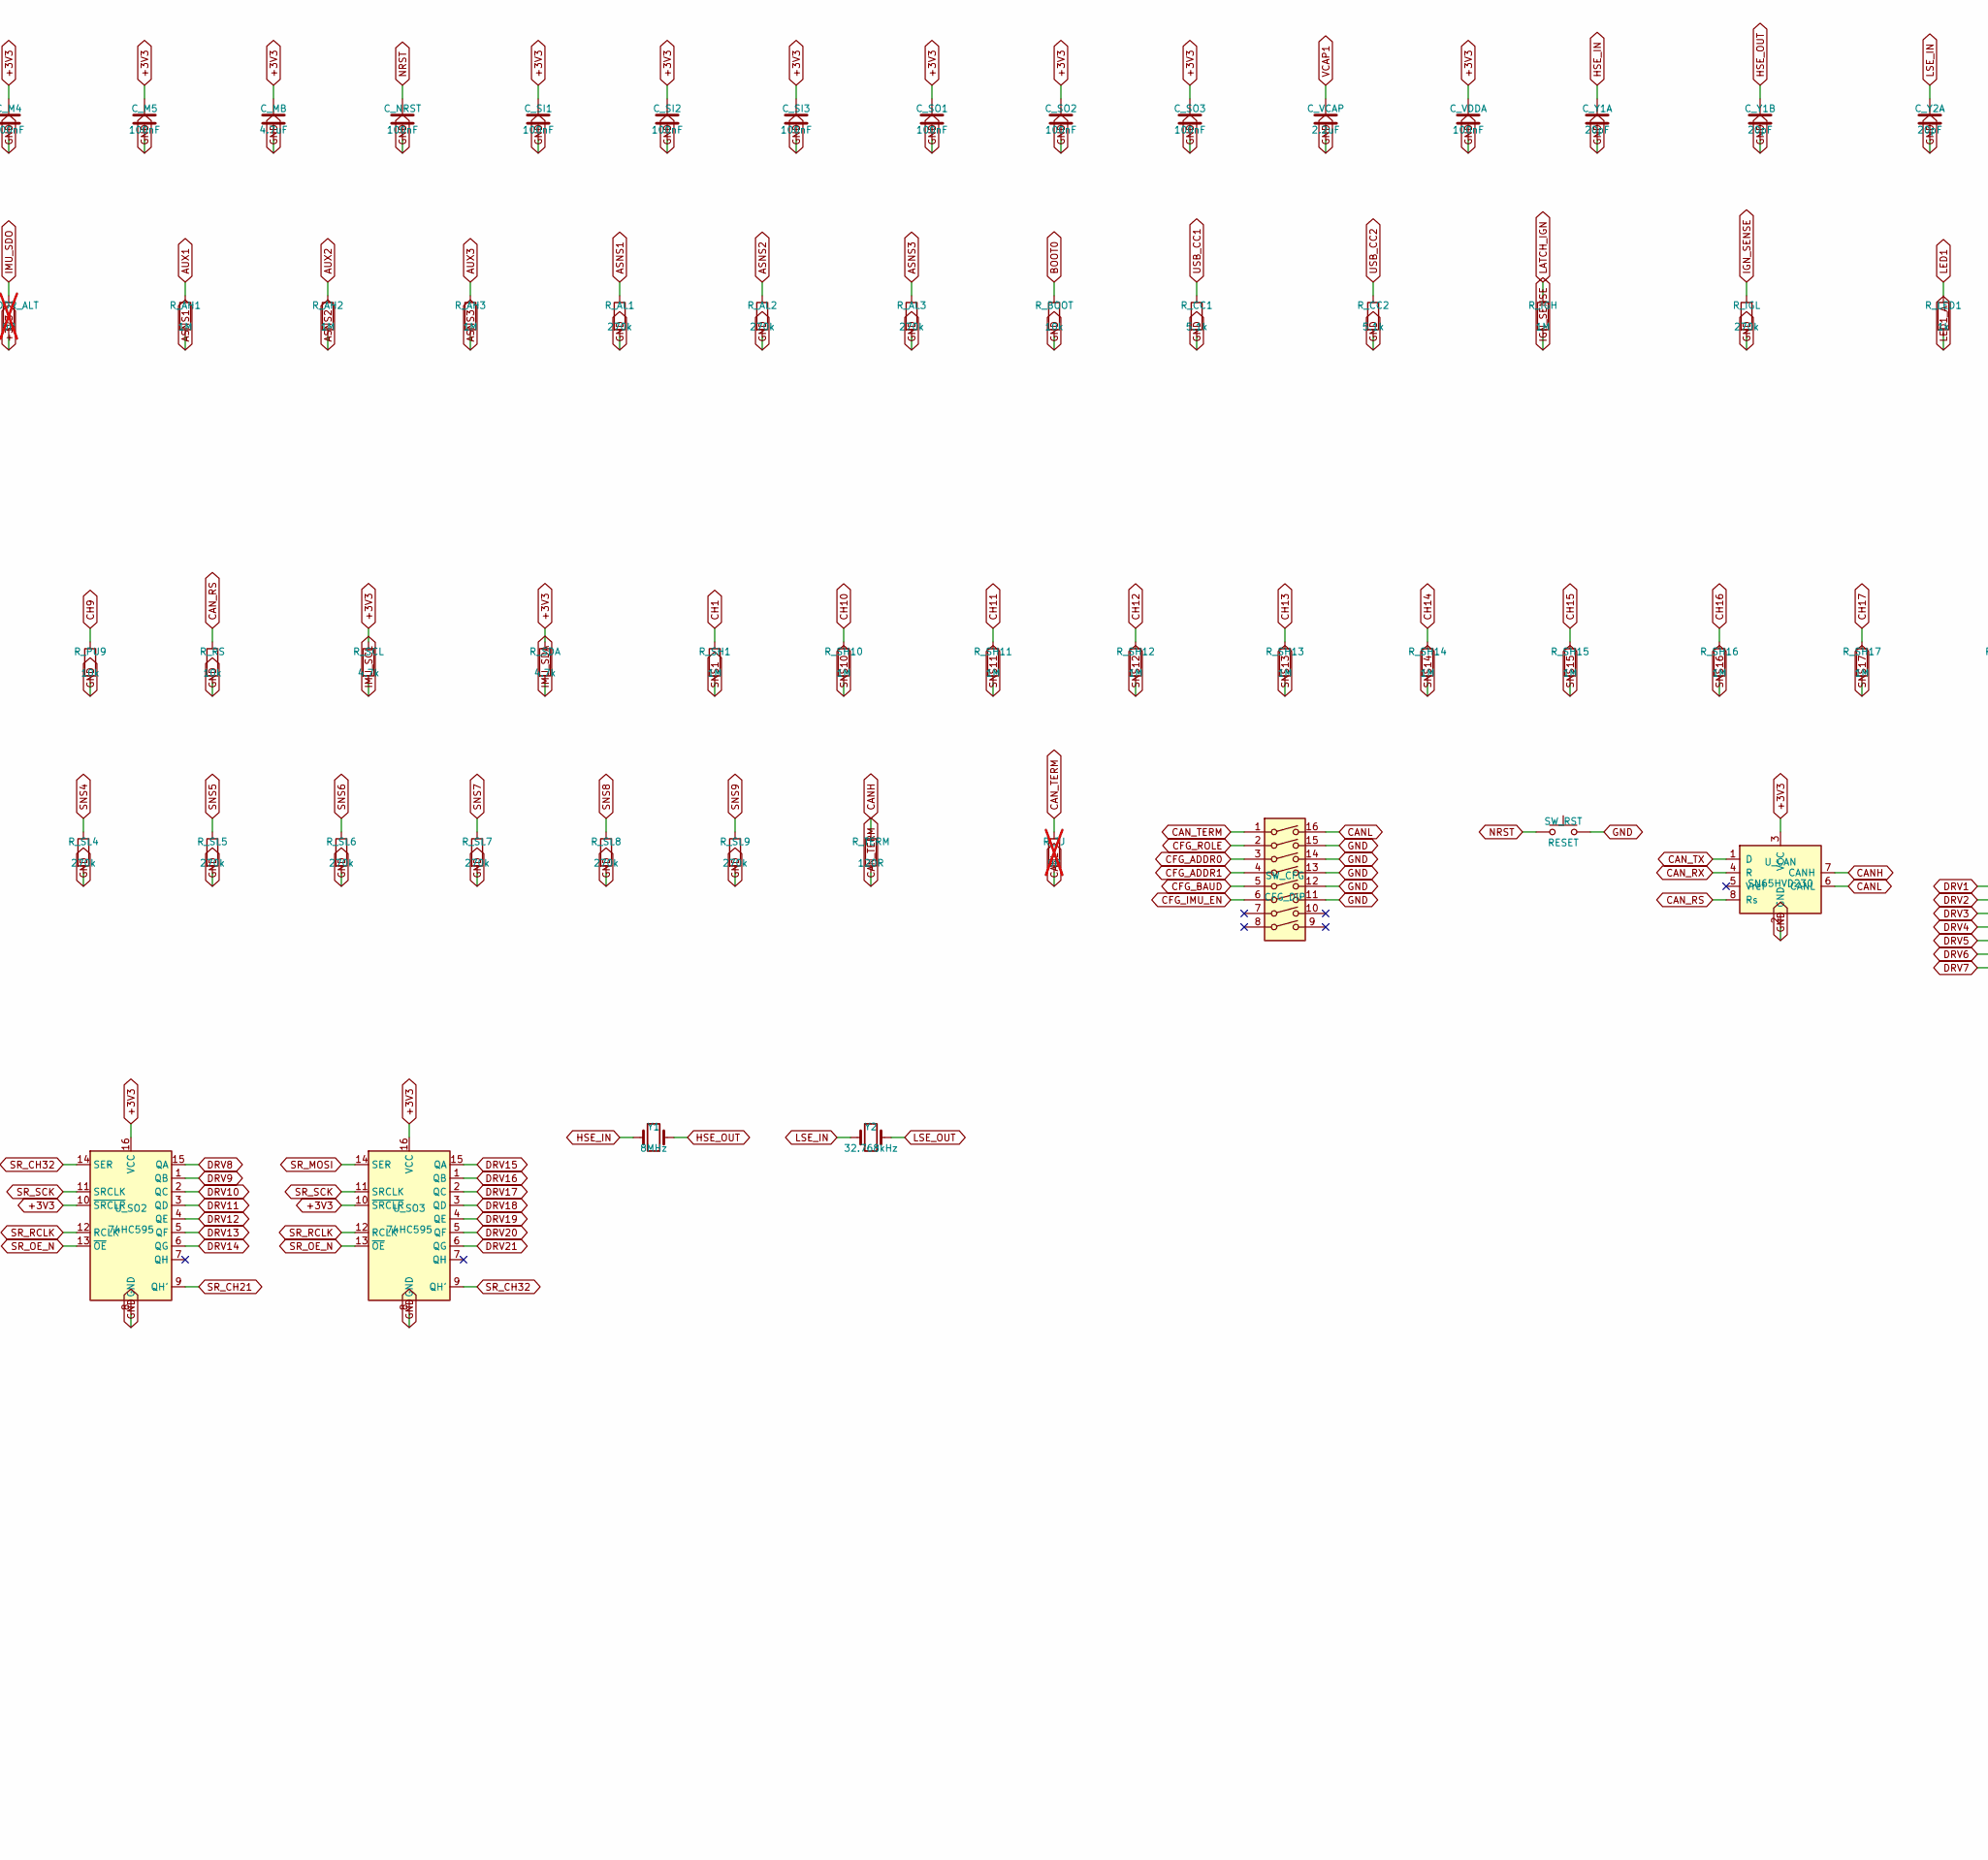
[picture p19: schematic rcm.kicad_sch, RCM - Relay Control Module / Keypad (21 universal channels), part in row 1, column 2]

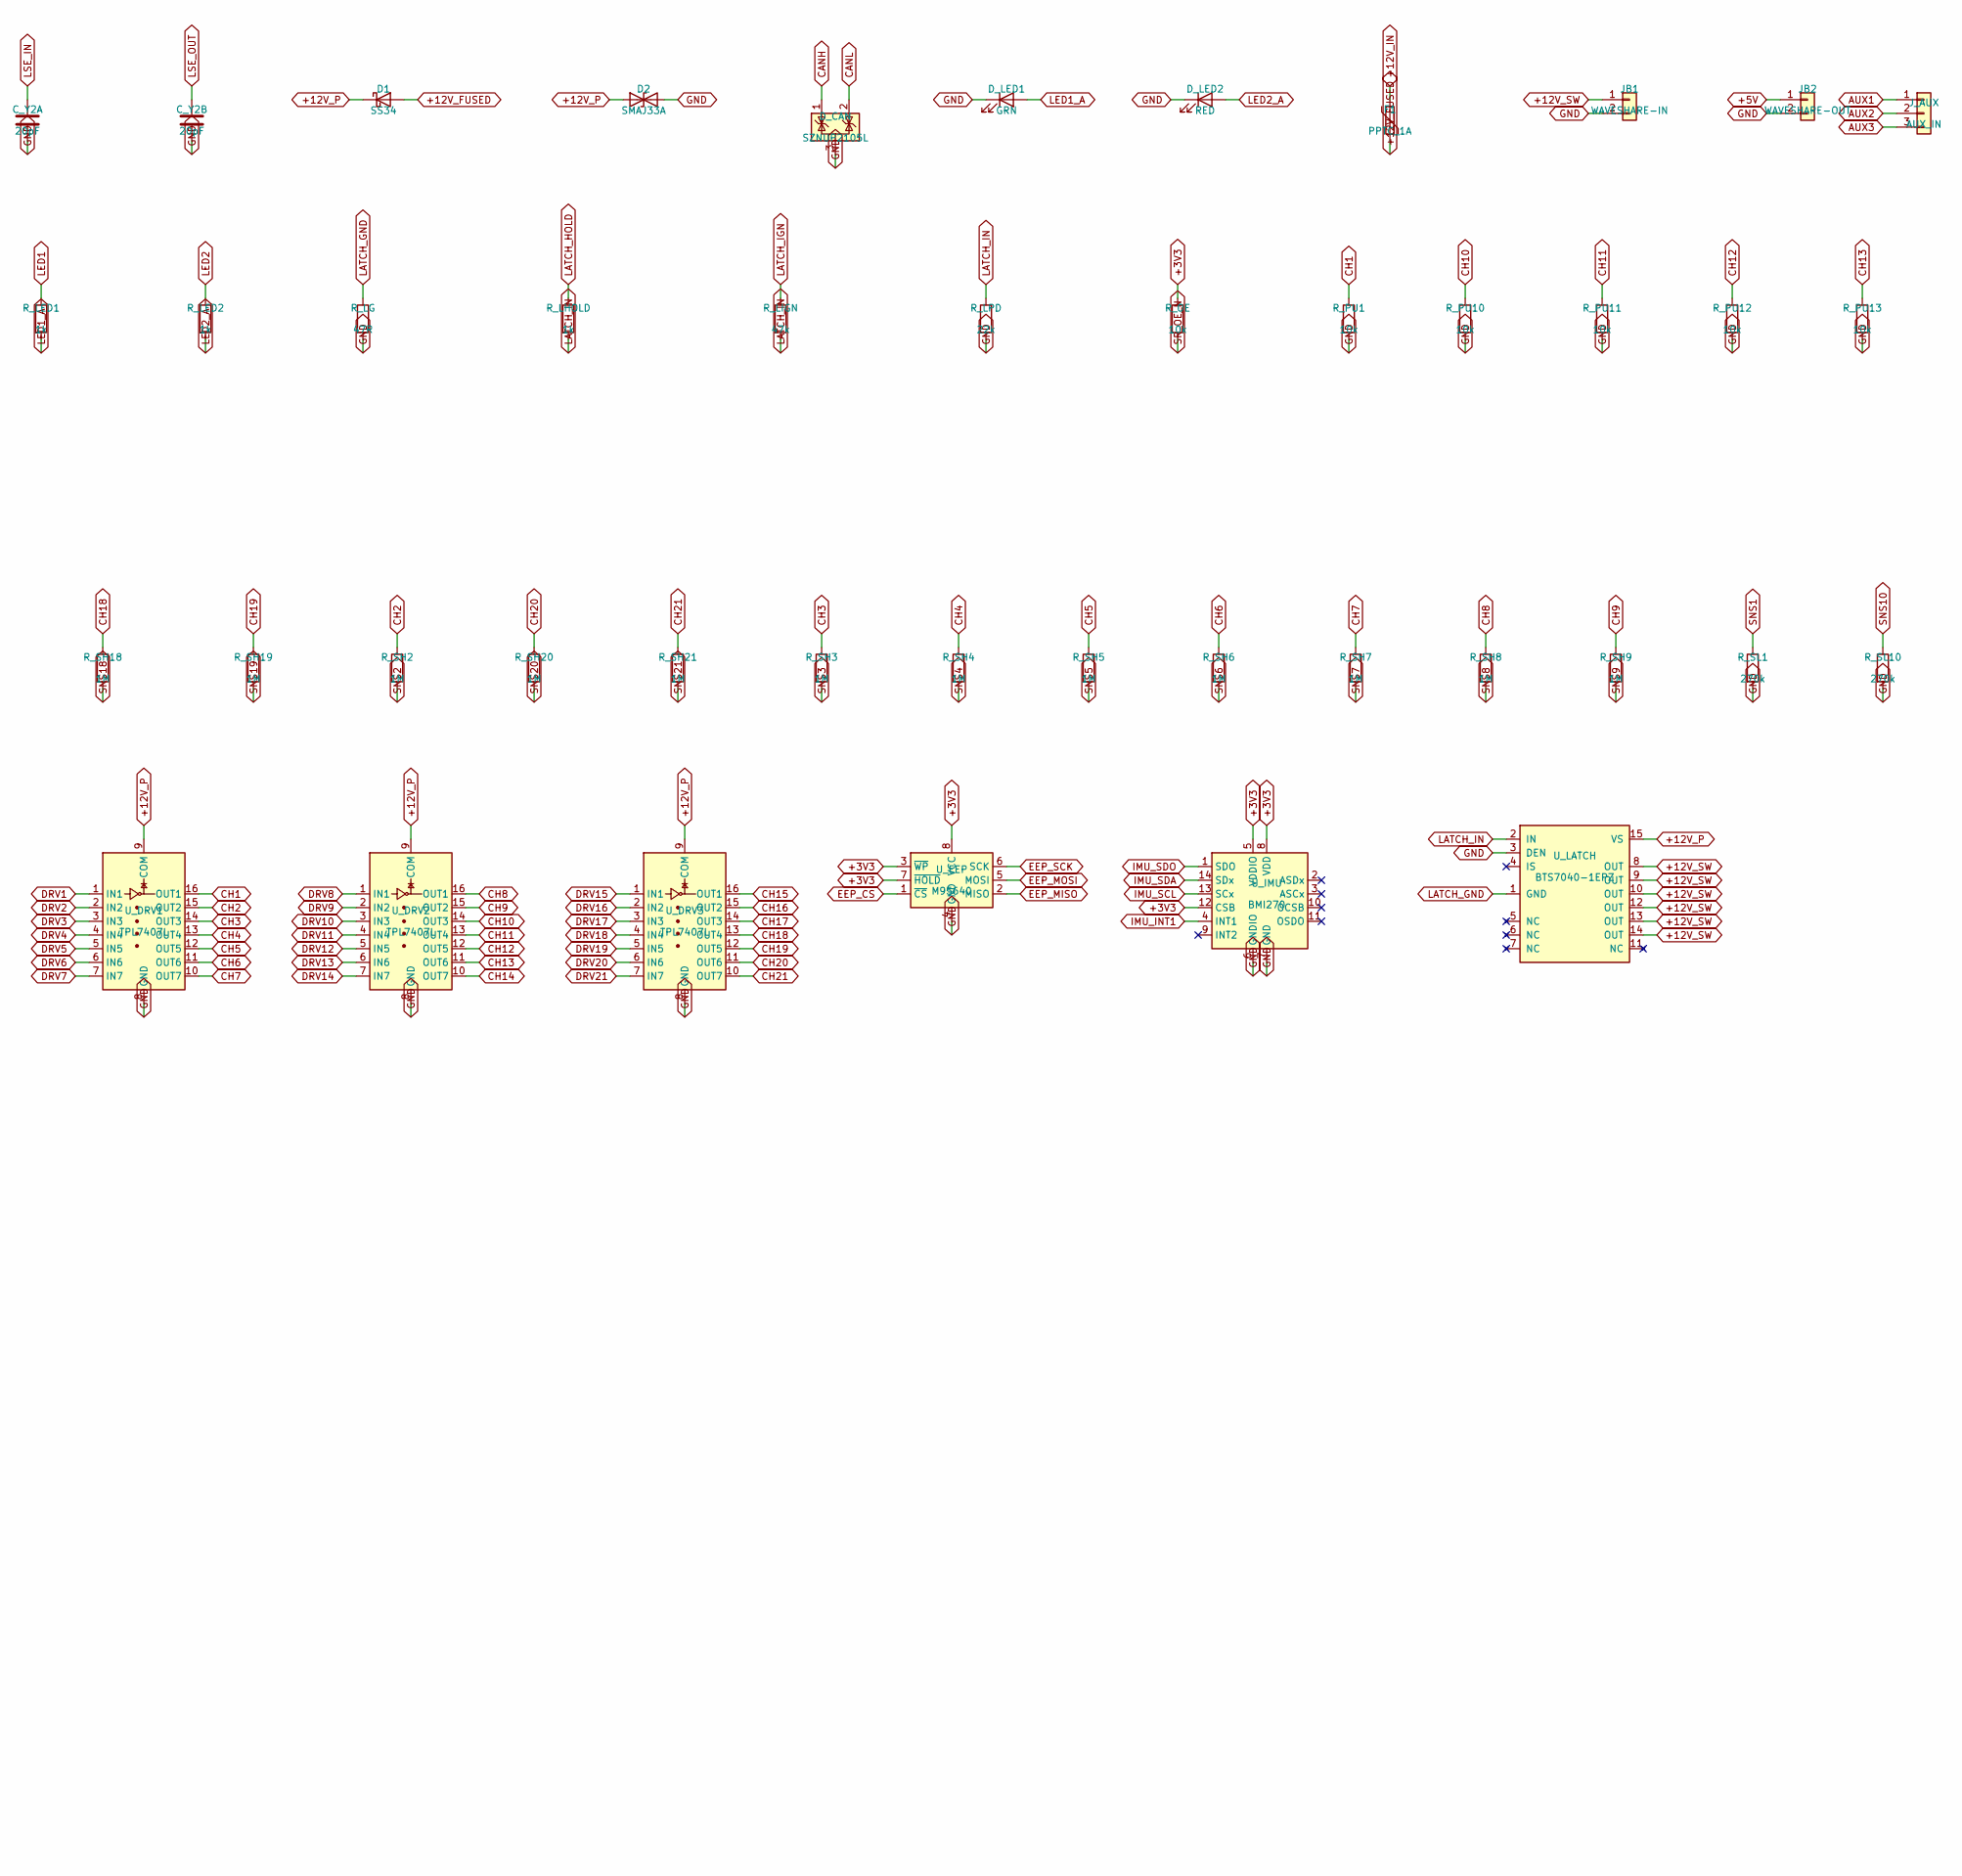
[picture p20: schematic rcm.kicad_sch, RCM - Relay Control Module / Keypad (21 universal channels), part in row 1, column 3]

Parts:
C_3V3I, C_5V: 10uF_25V; C_0805_2012Metric; LCSC C15850
C_3V3O: 100nF; C_0805_2012Metric; LCSC C49678
C_BULK: 10uF_50V; C_1210_3225Metric; LCSC C2918502
C_CAN: 100nF; C_0805_2012Metric; LCSC C49678
C_EEP: 100nF; C_0805_2012Metric; LCSC C49678
C_IMU1, C_IMU2: 100nF; C_0805_2012Metric; LCSC C49678
C_LSW: 100nF; C_0805_2012Metric; LCSC C49678
C_LVS: 100nF; C_0805_2012Metric; LCSC C49678
C_M1, C_M2, C_M3, C_M4, C_M5: 100nF; C_0805_2012Metric; LCSC C49678
C_MB: 4.7uF; C_0805_2012Metric; LCSC C1779
C_NRST: 100nF; C_0805_2012Metric; LCSC C49678
C_SI1, C_SI2, C_SI3: 100nF; C_0805_2012Metric; LCSC C49678
C_SO1, C_SO2, C_SO3: 100nF; C_0805_2012Metric; LCSC C49678
C_VCAP: 2.2uF; C_0805_2012Metric; LCSC C377773
C_VDDA: 100nF; C_0805_2012Metric; LCSC C49678
C_Y1A, C_Y1B, C_Y2A, C_Y2B: 20pF; C_0805_2012Metric; LCSC C1798
D1: SS34; D_SMA; LCSC C8678
D2: SMAJ33A; D_SMA; LCSC C353454
D_CAN: SZNUP2105L; SOT-23; LCSC C233494
D_LED1: GRN; LED_0805_2012Metric; LCSC C84260
D_LED2: RED; LED_0805_2012Metric; LCSC C84256
F1: PPTC_1A; R_1812_4532Metric; LCSC C19078719
JB1: WAVESHARE-IN; WaveshareBuck_IN_2x2_P3.50mm
JB2: WAVESHARE-OUT; WaveshareBuck_OUT_3x3_P2.54mm; LCSC C37208
J_AUX: AUX_IN; TerminalBlock_KF2EDG-3.5-3P_1x03_P3.50mm_Horizontal; LCSC C441322
J_BOOT: BOOT_SEL; PinHeader_1x03_P2.54mm_Vertical; LCSC C2937625
J_CAN1: CAN_A; TerminalBlock_KF2EDG-3.5-3P_1x03_P3.50mm_Horizontal; LCSC C441322
J_CAN2: CAN_B; TerminalBlock_KF2EDG-3.5-3P_1x03_P3.50mm_Horizontal; LCSC C441322
J_CH1: CH1-7; TerminalBlock_KF2EDG-3.5-7P_1x07_P3.50mm_Horizontal; LCSC C441326
J_CH2: CH8-14; TerminalBlock_KF2EDG-3.5-7P_1x07_P3.50mm_Horizontal; LCSC C441326
J_CH3: CH15-21; TerminalBlock_KF2EDG-3.5-7P_1x07_P3.50mm_Horizontal; LCSC C441326
J_IGN: IGN_IN; TerminalBlock_KF2EDG-3.5-2P_1x02_P3.50mm_Horizontal; LCSC C441321
J_PWR: PWR_IN; TerminalBlock_KF2EDG-3.5-2P_1x02_P3.50mm_Horizontal; LCSC C441321
J_SWD: SWD; PinHeader_1x05_P2.54mm_Vertical; LCSC C492404
J_USB: USB-C; USB_C_Receptacle_HCTL_HC-TYPE-C-16P-01A; LCSC C165948
R_ADDR: 0R; R_0805_2012Metric; LCSC C17477
R_ADDR_ALT: 0R; R_0805_2012Metric; LCSC C17477; not fitted
R_AH1, R_AH2, R_AH3: 1M; R_0805_2012Metric; LCSC C17514
R_AL1, R_AL2, R_AL3: 270k; R_0805_2012Metric; LCSC C17589
R_BOOT: 10k; R_0805_2012Metric; LCSC C17414
R_CC1, R_CC2: 5.1k; R_0805_2012Metric; LCSC C27834
R_IGH: 1M; R_0805_2012Metric; LCSC C17514
R_IGL: 270k; R_0805_2012Metric; LCSC C17589
R_LED1, R_LED2: 1k; R_0805_2012Metric; LCSC C17513
R_LG: 47R; R_0805_2012Metric; LCSC C17714
R_LHOLD: 1k; R_0805_2012Metric; LCSC C17513
R_LIGN: 47k; R_0805_2012Metric; LCSC C17713
R_LPD: 22k; R_0805_2012Metric; LCSC C17560
R_OE: 10k; R_0805_2012Metric; LCSC C17414
R_PU1, R_PU2, R_PU3, R_PU4, R_PU5, R_PU6, R_PU7, R_PU8, R_PU9, R_PU10, R_PU11, R_PU12, R_PU13, R_PU14, R_PU15, R_PU16, R_PU17, R_PU18, R_PU19, R_PU20, R_PU21: 10k; R_0805_2012Metric; LCSC C17414
R_RS: 10k; R_0805_2012Metric; LCSC C17414
R_SCL: 4.7k; R_0805_2012Metric; LCSC C17673
R_SDA: 4.7k; R_0805_2012Metric; LCSC C17673
R_SH1, R_SH2, R_SH3, R_SH4, R_SH5, R_SH6, R_SH7, R_SH8, R_SH9, R_SH10, R_SH11, R_SH12, R_SH13, R_SH14, R_SH15, R_SH16, R_SH17, R_SH18, R_SH19, R_SH20, R_SH21: 1M; R_0805_2012Metric; LCSC C17514
R_SL1, R_SL2, R_SL3, R_SL4, R_SL5, R_SL6, R_SL7, R_SL8, R_SL9, R_SL10, R_SL11, R_SL12, R_SL13, R_SL14, R_SL15, R_SL16, R_SL17, R_SL18, R_SL19, R_SL20, R_SL21: 270k; R_0805_2012Metric; LCSC C17589
R_TERM: 120R; R_0805_2012Metric; LCSC C17437
R_TJ: 0R; R_0805_2012Metric; LCSC C17477; not fitted
SW_CFG: CFG_DIP; SW_DIP_SPSTx08_Slide_KingTek_DSHP08TS_W7.62mm_P1.27mm; LCSC C6386921
SW_RST: RESET; SW_SPST_TL3342; LCSC C2886894
U_CAN: SN65HVD230; SOIC-8_3.9x4.9mm_P1.27mm; LCSC C12084
U_DRV1, U_DRV2, U_DRV3: TPL7407L; TSSOP-16_4.4x5mm_P0.65mm; LCSC C2149827
U_EEP: M95640; SOIC-8_3.9x4.9mm_P1.27mm; LCSC C283461
U_IMU: BMI270; Bosch_LGA-14_3x2.5mm_P0.5mm; LCSC C2836813
U_LATCH: BTS7040-1EPZ; Infineon_PG-TSDSO-14-22; LCSC C534838
U_LDO: AMS1117-3.3; SOT-223-3_TabPin2; LCSC C6186
U_MCU: STM32F446RET6; LQFP-64_10x10mm_P0.5mm; LCSC C69336
U_SI1, U_SI2, U_SI3: 74HC165; SOIC-16_3.9x9.9mm_P1.27mm; LCSC C22384789
U_SO1, U_SO2, U_SO3: 74HC595; SOIC-16_3.9x9.9mm_P1.27mm; LCSC C5947
Y1: 8MHz; Crystal_SMD_5032-2Pin_5.0x3.2mm; LCSC C115962
Y2: 32.768kHz; Crystal_SMD_3215-2Pin_3.2x1.5mm; LCSC C32346

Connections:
+3V3: C_3V3I.1, C_3V3O.1, C_CAN.1, C_EEP.1, C_IMU1.1, C_IMU2.1, C_M1.1, C_M2.1, C_M3.1, C_M4.1, C_M5.1, C_MB.1, C_SI1.1, C_SI2.1, C_SI3.1, C_SO1.1, C_SO2.1, C_SO3.1, C_VDDA.1, J_BOOT.1, J_SWD.1, R_ADDR_ALT.2, R_OE.1, R_SCL.1, R_SDA.1, U_CAN.3 (VCC), U_EEP.3 (~WP), U_EEP.7 (~HOLD), U_EEP.8 (VCC), U_IMU.5 (VDDIO), U_IMU.8 (VDD), U_IMU.12 (CSB), U_LDO.2 (VO), U_MCU.1 (VBAT), U_MCU.13 (VDDA), U_MCU.19 (VDD), U_MCU.32 (VDD), U_MCU.48 (VDD), U_MCU.64 (VDD), U_SI1.16 (VCC), U_SI2.16 (VCC), U_SI3.16 (VCC), U_SO1.10 (~SRCLR), U_SO1.16 (VCC), U_SO2.10 (~SRCLR), U_SO2.16 (VCC), U_SO3.10 (~SRCLR), U_SO3.16 (VCC)
+5V: C_5V.1, JB2.1, U_LDO.3 (VI)
+12V_FUSED: D1.2 (A), F1.2
+12V_IN: F1.1, J_PWR.1
+12V_P: C_BULK.1, C_LVS.1, D1.1 (K), D2.1 (A1), U_DRV1.9 (COM), U_DRV2.9 (COM), U_DRV3.9 (COM), U_LATCH.15 (VS)
+12V_SW: C_LSW.1, JB1.1, U_LATCH.8 (OUT), U_LATCH.9 (OUT), U_LATCH.10 (OUT), U_LATCH.12 (OUT), U_LATCH.13 (OUT), U_LATCH.14 (OUT)
ASNS1: R_AH1.2, R_AL1.1, U_SI1.6 (D7)
ASNS2: R_AH2.2, R_AL2.1, U_SI2.6 (D7)
ASNS3: R_AH3.2, R_AL3.1, U_SI3.6 (D7)
AUX1: J_AUX.1, R_AH1.1
AUX2: J_AUX.2, R_AH2.1
AUX3: J_AUX.3, R_AH3.1
BOOT0: J_BOOT.2, R_BOOT.1, U_MCU.60 (BOOT0)
CANH: D_CAN.1 (K), J_CAN1.1, J_CAN2.1, R_TERM.1, U_CAN.7 (CANH)
CANL: D_CAN.2 (K), J_CAN1.2, J_CAN2.2, R_TJ.2, SW_CFG.16, U_CAN.6 (CANL)
CAN_RS: R_RS.1, U_CAN.8 (Rs)
CAN_RX: U_CAN.4 (R), U_MCU.61 (PB8)
CAN_TERM: R_TERM.2, R_TJ.1, SW_CFG.1
CAN_TX: U_CAN.1 (D), U_MCU.62 (PB9)
CFG_ADDR0: SW_CFG.3, U_MCU.9 (PC1)
CFG_ADDR1: SW_CFG.4, U_MCU.10 (PC2)
CFG_BAUD: SW_CFG.5, U_MCU.11 (PC3)
CFG_IMU_EN: SW_CFG.6, U_MCU.24 (PC4)
CFG_ROLE: SW_CFG.2, U_MCU.8 (PC0)
CH1: J_CH1.1, R_PU1.1, R_SH1.1, U_DRV1.16 (OUT1)
CH2: J_CH1.2, R_PU2.1, R_SH2.1, U_DRV1.15 (OUT2)
CH3: J_CH1.3, R_PU3.1, R_SH3.1, U_DRV1.14 (OUT3)
CH4: J_CH1.4, R_PU4.1, R_SH4.1, U_DRV1.13 (OUT4)
CH5: J_CH1.5, R_PU5.1, R_SH5.1, U_DRV1.12 (OUT5)
CH6: J_CH1.6, R_PU6.1, R_SH6.1, U_DRV1.11 (OUT6)
CH7: J_CH1.7, R_PU7.1, R_SH7.1, U_DRV1.10 (OUT7)
CH8: J_CH2.1, R_PU8.1, R_SH8.1, U_DRV2.16 (OUT1)
CH9: J_CH2.2, R_PU9.1, R_SH9.1, U_DRV2.15 (OUT2)
CH10: J_CH2.3, R_PU10.1, R_SH10.1, U_DRV2.14 (OUT3)
CH11: J_CH2.4, R_PU11.1, R_SH11.1, U_DRV2.13 (OUT4)
CH12: J_CH2.5, R_PU12.1, R_SH12.1, U_DRV2.12 (OUT5)
CH13: J_CH2.6, R_PU13.1, R_SH13.1, U_DRV2.11 (OUT6)
CH14: J_CH2.7, R_PU14.1, R_SH14.1, U_DRV2.10 (OUT7)
CH15: J_CH3.1, R_PU15.1, R_SH15.1, U_DRV3.16 (OUT1)
CH16: J_CH3.2, R_PU16.1, R_SH16.1, U_DRV3.15 (OUT2)
CH17: J_CH3.3, R_PU17.1, R_SH17.1, U_DRV3.14 (OUT3)
CH18: J_CH3.4, R_PU18.1, R_SH18.1, U_DRV3.13 (OUT4)
CH19: J_CH3.5, R_PU19.1, R_SH19.1, U_DRV3.12 (OUT5)
CH20: J_CH3.6, R_PU20.1, R_SH20.1, U_DRV3.11 (OUT6)
CH21: J_CH3.7, R_PU21.1, R_SH21.1, U_DRV3.10 (OUT7)
DRV1: U_DRV1.1 (IN1), U_SO1.15 (QA)
DRV2: U_DRV1.2 (IN2), U_SO1.1 (QB)
DRV3: U_DRV1.3 (IN3), U_SO1.2 (QC)
DRV4: U_DRV1.4 (IN4), U_SO1.3 (QD)
DRV5: U_DRV1.5 (IN5), U_SO1.4 (QE)
DRV6: U_DRV1.6 (IN6), U_SO1.5 (QF)
DRV7: U_DRV1.7 (IN7), U_SO1.6 (QG)
DRV8: U_DRV2.1 (IN1), U_SO2.15 (QA)
DRV9: U_DRV2.2 (IN2), U_SO2.1 (QB)
DRV10: U_DRV2.3 (IN3), U_SO2.2 (QC)
DRV11: U_DRV2.4 (IN4), U_SO2.3 (QD)
DRV12: U_DRV2.5 (IN5), U_SO2.4 (QE)
DRV13: U_DRV2.6 (IN6), U_SO2.5 (QF)
DRV14: U_DRV2.7 (IN7), U_SO2.6 (QG)
DRV15: U_DRV3.1 (IN1), U_SO3.15 (QA)
DRV16: U_DRV3.2 (IN2), U_SO3.1 (QB)
DRV17: U_DRV3.3 (IN3), U_SO3.2 (QC)
DRV18: U_DRV3.4 (IN4), U_SO3.3 (QD)
DRV19: U_DRV3.5 (IN5), U_SO3.4 (QE)
DRV20: U_DRV3.6 (IN6), U_SO3.5 (QF)
DRV21: U_DRV3.7 (IN7), U_SO3.6 (QG)
EEP_CS: U_EEP.1 (~CS), U_MCU.33 (PB12)
EEP_MISO: U_EEP.2 (MISO), U_MCU.35 (PB14)
EEP_MOSI: U_EEP.5 (MOSI), U_MCU.36 (PB15)
EEP_SCK: U_EEP.6 (SCK), U_MCU.34 (PB13)
GND: C_3V3I.2, C_3V3O.2, C_5V.2, C_BULK.2, C_CAN.2, C_EEP.2, C_IMU1.2, C_IMU2.2, C_LSW.2, C_LVS.2, C_M1.2, C_M2.2, C_M3.2, C_M4.2, C_M5.2, C_MB.2, C_NRST.2, C_SI1.2, C_SI2.2, C_SI3.2, C_SO1.2, C_SO2.2, C_SO3.2, C_VCAP.2, C_VDDA.2, C_Y1A.2, C_Y1B.2, C_Y2A.2, C_Y2B.2, D2.2 (A2), D_CAN.3 (A), D_LED1.1 (K), D_LED2.1 (K), JB1.2, JB2.2, J_BOOT.3, J_CAN1.3, J_CAN2.3, J_IGN.2, J_PWR.2, J_SWD.5, J_USB.A1 (GND), J_USB.A12 (GND), J_USB.B1 (GND), J_USB.B12 (GND), J_USB.SH (SHIELD), R_ADDR.2, R_AL1.2, R_AL2.2, R_AL3.2, R_BOOT.2, R_CC1.2, R_CC2.2, R_IGL.2, R_LG.2, R_LPD.2, R_PU1.2, R_PU2.2, R_PU3.2, R_PU4.2, R_PU5.2, R_PU6.2, R_PU7.2, R_PU8.2, R_PU9.2, R_PU10.2, R_PU11.2, R_PU12.2, R_PU13.2, R_PU14.2, R_PU15.2, R_PU16.2, R_PU17.2, R_PU18.2, R_PU19.2, R_PU20.2, R_PU21.2, R_RS.2, R_SL1.2, R_SL2.2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
HSE_IN: C_Y1A.1, U_MCU.5 (PH0), Y1.1
HSE_OUT: C_Y1B.1, U_MCU.6 (PH1), Y1.2
IGN_SENSE: R_IGH.2, R_IGL.1, U_MCU.14 (PA0)
IMU_INT1: U_IMU.4 (INT1), U_MCU.15 (PA1)
IMU_SCL: R_SCL.2, U_IMU.13 (SCx), U_MCU.58 (PB6)
IMU_SDA: R_SDA.2, U_IMU.14 (SDx), U_MCU.59 (PB7)
IMU_SDO: R_ADDR.1, R_ADDR_ALT.1, U_IMU.1 (SDO)
LATCH_GND: R_LG.1, U_LATCH.1 (GND)
LATCH_HOLD: R_LHOLD.1, U_MCU.29 (PB10)
LATCH_IGN: J_IGN.1, R_IGH.1, R_LIGN.1
LATCH_IN: R_LHOLD.2, R_LIGN.2, R_LPD.1, U_LATCH.2 (IN)
LED1: R_LED1.1, U_MCU.41 (PA8)
LED1_A: D_LED1.2 (A), R_LED1.2
LED2: R_LED2.1, U_MCU.57 (PB5)
LED2_A: D_LED2.2 (A), R_LED2.2
LSE_IN: C_Y2A.1, U_MCU.3 (PC14), Y2.1
LSE_OUT: C_Y2B.1, U_MCU.4 (PC15), Y2.2
NRST: C_NRST.1, J_SWD.4, SW_RST.1, U_MCU.7 (NRST)
SNS1: R_SH1.2, R_SL1.1, U_SI1.11 (D0)
SNS2: R_SH2.2, R_SL2.1, U_SI1.12 (D1)
SNS3: R_SH3.2, R_SL3.1, U_SI1.13 (D2)
SNS4: R_SH4.2, R_SL4.1, U_SI1.14 (D3)
SNS5: R_SH5.2, R_SL5.1, U_SI1.3 (D4)
SNS6: R_SH6.2, R_SL6.1, U_SI1.4 (D5)
SNS7: R_SH7.2, R_SL7.1, U_SI1.5 (D6)
SNS8: R_SH8.2, R_SL8.1, U_SI2.11 (D0)
SNS9: R_SH9.2, R_SL9.1, U_SI2.12 (D1)
SNS10: R_SH10.2, R_SL10.1, U_SI2.13 (D2)
SNS11: R_SH11.2, R_SL11.1, U_SI2.14 (D3)
SNS12: R_SH12.2, R_SL12.1, U_SI2.3 (D4)
SNS13: R_SH13.2, R_SL13.1, U_SI2.4 (D5)
SNS14: R_SH14.2, R_SL14.1, U_SI2.5 (D6)
SNS15: R_SH15.2, R_SL15.1, U_SI3.11 (D0)
SNS16: R_SH16.2, R_SL16.1, U_SI3.12 (D1)
SNS17: R_SH17.2, R_SL17.1, U_SI3.13 (D2)
SNS18: R_SH18.2, R_SL18.1, U_SI3.14 (D3)
SNS19: R_SH19.2, R_SL19.1, U_SI3.3 (D4)
SNS20: R_SH20.2, R_SL20.1, U_SI3.4 (D5)
SNS21: R_SH21.2, R_SL21.1, U_SI3.5 (D6)
SR_CH21: U_SO1.14 (SER), U_SO2.9 (QH')
SR_CH32: U_SO2.14 (SER), U_SO3.9 (QH')
SR_DI12: U_SI1.9 (Q7), U_SI2.10 (DS)
SR_DI23: U_SI2.9 (Q7), U_SI3.10 (DS)
SR_MISO: U_MCU.22 (PA6), U_SI3.9 (Q7)
SR_MOSI: U_MCU.23 (PA7), U_SO3.14 (SER)
SR_OE_N: R_OE.2, U_MCU.28 (PB2), U_SO1.13 (~OE), U_SO2.13 (~OE), U_SO3.13 (~OE)
SR_PL: U_MCU.27 (PB1), U_SI1.1 (~PL), U_SI2.1 (~PL), U_SI3.1 (~PL)
SR_RCLK: U_MCU.26 (PB0), U_SO1.12 (RCLK), U_SO2.12 (RCLK), U_SO3.12 (RCLK)
SR_SCK: U_MCU.21 (PA5), U_SI1.2 (CP), U_SI2.2 (CP), U_SI3.2 (CP), U_SO1.11 (SRCLK), U_SO2.11 (SRCLK), U_SO3.11 (SRCLK)
SWCLK: J_SWD.3, U_MCU.49 (PA14)
SWDIO: J_SWD.2, U_MCU.46 (PA13)
USB_CC1: J_USB.A5 (CC1), R_CC1.1
USB_CC2: J_USB.B5 (CC2), R_CC2.1
USB_DM: J_USB.A7 (D-), J_USB.B7 (D-), U_MCU.44 (PA11)
USB_DP: J_USB.A6 (D+), J_USB.B6 (D+), U_MCU.45 (PA12)
USB_VBUS: J_USB.A4 (VBUS), J_USB.A9 (VBUS), J_USB.B4 (VBUS), J_USB.B9 (VBUS)
VCAP1: C_VCAP.1, U_MCU.30 (VCAP_1)

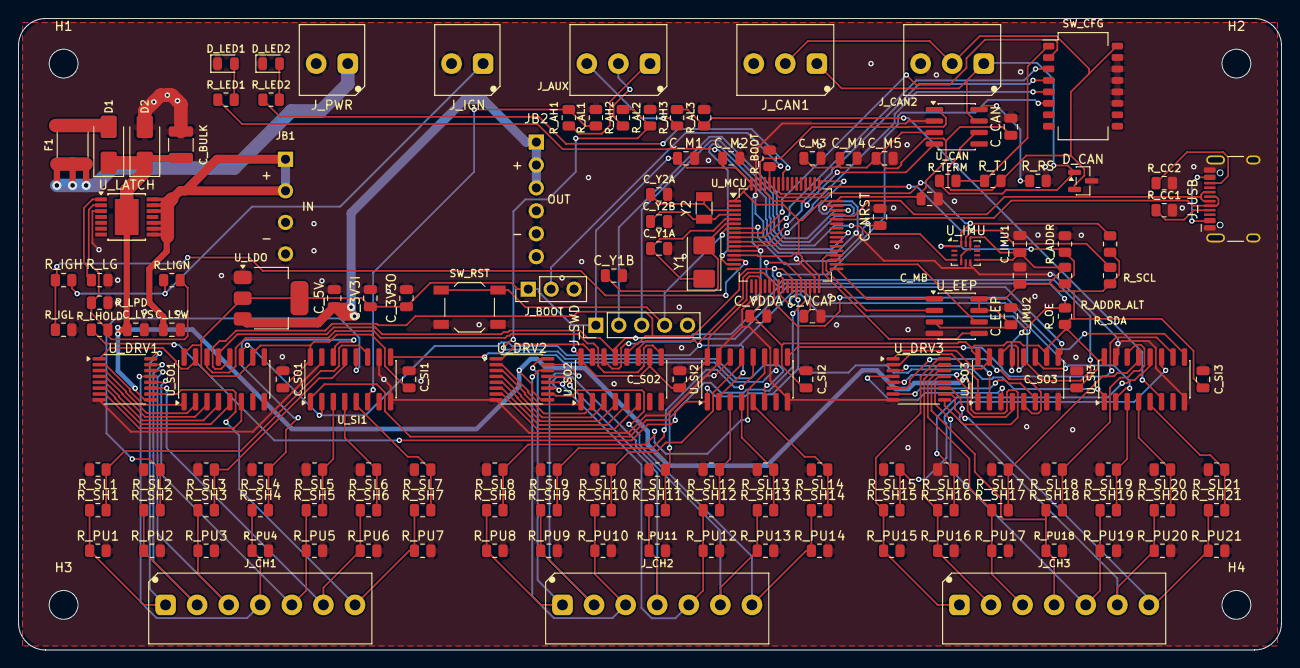
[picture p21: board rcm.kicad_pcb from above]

Board: 4 copper layers, 140.0 x 70.0 mm, 159 parts (0 on the bottom side), 128 nets.

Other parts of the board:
H1, H2, H3, H4: MountingHole_3.2mm_M3

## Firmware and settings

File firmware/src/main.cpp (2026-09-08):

/*
 * RCM firmware -- main.
 *
 * ===========================================================================
 * BOOT ORDER IS A SAFETY PROPERTY, NOT A STYLE CHOICE
 * ===========================================================================
 * Two things must happen before anything else, in this order:
 *
 *   1. LATCH_HOLD high. Until it is, the board is alive only for as long as the
 *      ignition signal is, and it will cut out mid-boot the moment you switch off.
 *      Nothing is debuggable before this works.
 *
 *   2. The shift registers get a zeroed frame shifted out and LATCHED, with
 *      SR_OE_N still high. Only then may the outputs be enabled. R_OE holds the
 *      595s in high-impedance from the instant power arrives; that is what stops
 *      21 relays clacking on during boot, and it is trivially easy to defeat by
 *      enabling the outputs one line too early.
 *
 * Everything after that can fail without taking the board down. A missing EEPROM
 * gives you defaults, a missing IMU gives you no IMU, and a CAN bitrate that cannot
 * be produced gives you a board that blinks an error but still runs its channels.
 *
 * ===========================================================================
 * SCHEDULING
 * ===========================================================================
 * A plain cooperative loop with millis() deadlines. No RTOS: the work is a 5ms I/O
 * tick, a 50ms broadcast and a 20ms IMU read, none of it is long, and a scheduler
 * that can be understood by reading forty lines is worth more here than one that
 * can preempt.
 *
 * The one hard rule is that ch_tick() must not be starved -- it is what feeds the
 * watchdog, and it is what turns relays on and off.
 */
#include <Arduino.h>
#include <IWatchdog.h>
#include "app.h"
#include "board.h"
#include "canbus.h"
#include "channels.h"
#include "config.h"
#include "ignition.h"
#include "imu.h"
#include "protocol.h"
#include "shiftreg.h"
#include "store.h"

#define TICK_MS      5      /* must match channels.cpp */
#define WDG_US  200000      /* 200ms; 40 missed ticks */

/* Ignition sense: J_IGN -> 1M/270k -> PA0. The divider ratio is 270/1270, so the
 * pin sees 21.26% of the ignition feed and the ADC saturates at about 15.5V. That
 * is a deliberate limitation -- the question being asked is "is the ignition on",
 * not "what exactly is the battery doing" -- but it does mean a reading pinned at
 * 15.5V means "at least 15.5V" and nothing more precise. */
#define IGN_NUM      1270L
#define IGN_DEN       270L
#define IGN_ON_MV    6000   /* below this the ignition input is considered open */

static bool     outputs_live;
static bool     eeprom_ok;
static bool     can_up;
static uint16_t ign_mv;

static uint32_t next_tick, next_bcast, next_imu, next_slow;

/* --- app.h ---------------------------------------------------------------- */

bool app_outputs_live(void) { return outputs_live; }

void app_set_outputs_live(bool live)
{
    /* Going live is only ever allowed to happen with a known state already latched
     * into the 595s -- which sr_begin() guarantees before this can first be called. */
    outputs_live = live;
    sr_outputs_enable(live);
}

bool     app_eeprom_ok(void)   { return eeprom_ok; }
uint16_t app_ignition_mv(void) { return ign_mv; }
bool     app_ignition_on(void) { return ign_mv >= IGN_ON_MV; }

/* --- LEDs ------------------------------------------------------------------
 * LED1 (green): SOLID means well. It only flashes to tell you something, so a glance
 * across a workshop separates "fine" from "look at me" without counting blink rates.
 * LED2 (red): faults, and only faults worth acting on.
 *
 * Both rules exist because the previous version cried wolf. Green went frantic whenever
 * the bus was quiet -- but a keypad is never commanded, it REPORTS, so a quiet bus is
 * its normal condition and it flashed fast forever. Red lit for an open circuit on any
 * channel, including the eighteen nobody has wired yet, so every bench board sat there
 * with a fault lamp on. An indicator that is always on tells you nothing at all.
 */
#define LEVEL_SHOW_MS  3000u   /* how long the result stays on screen        */
#define LEVEL_PAUSE_MS  400u   /* silence between the hold and the answer    */
#define LEVEL_BLINK_MS  400u   /* one counted blink: 200 on, 200 off         */

static void leds(uint32_t now)
{
    /* Only outputs that have been given a job can meaningfully be faulty -- see
     * ch_fault_actionable(), which the CAN status flag uses too so the lamp and the bus
     * cannot tell you different things. */
    const bool fault = ch_fault_actionable();

    /* --- auto-levelling: acknowledge the press, then report the result ---
     * Held switch  -> green/red alternate at 2 Hz, for as long as it is held. That says
     *                 "seen, keep holding", and releasing early aborts visibly. Without
     *                 it you hold a switch for two seconds unsure whether anything
     *                 registered, and a press that missed looks like one still waiting.
     * Then a pause, then the answer, counted in blinks because a count is readable
     * lying under a dash where a colour alone is not:
     *     green x4  levelled
     *     red   x2  moving -- stop moving and try again
     *     red   x3  not square -- retrying will not help, the MOUNT is wrong
     *     red   x4  no IMU -- hardware or the CFG_IMU_EN strap
     * The refusals are counted separately on purpose. Collapsing them to one pattern
     * would make a raked mount look like someone leaning on the car, and you would
     * retry forever at something no amount of retrying can fix. */
    /* A save shows as a quick double-blink of BOTH lamps -- deliberately unlike the
     * calibration answers, because it is a different kind of event and nothing else
     * about the board changes to confirm it happened. */
    const uint32_t sv_at = proto_saved_when();
    if (sv_at && (uint32_t)(now - sv_at) < LEVEL_SHOW_MS) {
        const uint32_t t  = now - sv_at;
        const bool     ok = proto_saved_ok();
        /* BOTH lamps together, twice. Deliberately unlike every calibration answer,
         * which are single-colour counts: a save is a different KIND of event, and a
         * green x2 would sit one blink away from the green x4 of a good calibration --
         * a difference nobody should have to count carefully under a dash. A FAILED
         * save is red x5, a count no other pattern uses. */
        const uint8_t n  = ok ? 2 : 5;
        const bool    on = (t / 300) < n && (t % 300) < 150;
        digitalWrite(PIN_LED1, (on && ok) ? HIGH : LOW);
        digitalWrite(PIN_LED2, on ? HIGH : LOW);
        return;
    }

    const uint32_t lvl_at = imu_level_when();
    if (lvl_at && (uint32_t)(now - lvl_at) < LEVEL_SHOW_MS) {
        const uint32_t age = now - lvl_at;
        if (age < LEVEL_PAUSE_MS) {            /* the beat of silence before the answer */
            digitalWrite(PIN_LED1, LOW);
            digitalWrite(PIN_LED2, LOW);
            return;
        }
        const uint32_t t    = age - LEVEL_PAUSE_MS;
        const uint8_t  res  = imu_level_result();
        const bool     ok   = (res == RCM_IMU_LEVEL_OK);
        const uint8_t  n    = ok ? 4 : (res == RCM_IMU_LEVEL_MOVING ? 2
                                     : (res == RCM_IMU_LEVEL_TILTED ? 3 : 4));
        const bool on = (t / LEVEL_BLINK_MS) < n && (t % LEVEL_BLINK_MS) < (LEVEL_BLINK_MS / 2);
        digitalWrite(PIN_LED1, (ok  && on) ? HIGH : LOW);
        digitalWrite(PIN_LED2, (!ok && on) ? HIGH : LOW);
        return;
    }

    if (proto_aux_level_holding()) {
        const bool phase = (now % 500) < 250;          /* 2 Hz, the two swapping */
        digitalWrite(PIN_LED1, phase ? HIGH : LOW);
        digitalWrite(PIN_LED2, phase ? LOW  : HIGH);
        return;
    }

    bool green;
    if (!can_up) {
        /* The controller itself never started -- a wrong bitrate or worse. Distinct from
         * losing a working bus, and worth its own frantic rate. */
        green = (now % 150) < 75;
    } else if (proto_failsafe() && proto_ever_addressed()) {
        /* Something WAS commanding this board and stopped. Only alarming because it was
         * loud before: see proto_ever_addressed(). */
        green = (now % 1000) < 500;                   /* 1 Hz */
    } else {
        green = true;                                 /* solid: all well */
    }

    digitalWrite(PIN_LED1, green ? HIGH : LOW);
    digitalWrite(PIN_LED2, fault ? (((now % 400) < 200) ? HIGH : LOW) : LOW);
}

/* Below this the channel sense divider cannot tell a healthy coil circuit from an open
 * one -- see ch_inhibit_diag(). 11.5V leaves a little margin over the ~11.0V where the
 * 74HC165 stops seeing a HIGH. The ignition feed is the only supply the board can
 * measure, but it comes off the same battery as the coils, so it tracks. */
#define DIAG_MIN_MV 11500

static void read_ignition(void)
{
    const uint32_t raw = analogRead(PIN_IGN_SENSE);           /* 12-bit */
    const uint32_t mv  = (raw * 3300UL) / 4095UL;
    ign_mv = (uint16_t)((mv * IGN_NUM) / IGN_DEN);

    /* Cranking drags the battery down far enough to make every un-driven output look
     * like a blown fuse. Stop diagnosing rather than report a boardful of faults. */
    ch_inhibit_diag(ign_mv < DIAG_MIN_MV);
}

/* --- shutdown --------------------------------------------------------------
 * The whole reason the board holds its own power on: when the ignition goes away
 * we get to put the outputs down deliberately and save anything that needs saving
 * before dropping LATCH_HOLD and switching ourselves off.
 */
static void shutdown_check(uint32_t now)
{
    /* WHEN to shut down is ignition.cpp's decision now -- a level going away, or a
     * button gesture. This function only knows HOW. */
    if (!ign_wants_shutdown()) return;

    /* The RUN output has already gone; ignition.cpp drops it the moment a stop is
     * requested. Hold everything ELSE up for a moment so the ECU can see ignition-off
     * and finish its own shutdown -- park the throttle, run the fan down, write back
     * whatever it has learned. Yanking the rail instantly would be the equivalent of
     * pulling the battery lead, every single time you switch the car off. */
    if ((now - ign_shutdown_since()) >= cfg.ign_shutdown_ms) {
        ch_all_off();
        sr_exchange();                 /* make sure the zeros actually reach the pins */
        sr_outputs_enable(false);
        digitalWrite(PIN_LED1, LOW);
        digitalWrite(PIN_LED2, LOW);
    }

    /* Everything is down, but cutting our own power still has to wait for the button
     * to be released -- with it held, dropping LATCH_HOLD power-CYCLES the board rather
     * than switching it off. See ign_may_cut_power(). */
    if (!ign_may_cut_power(now)) return;

    digitalWrite(PIN_LATCH_HOLD, LOW); /* goodnight */

    /* Wait for the rail to collapse. The watchdog has to be fed while we do -- it is
     * a 200ms window and this wait is 250ms, so a plain delay() would reset the board
     * instead of letting it die. Feeding it here is not defeating the watchdog: if
     * the power really is going away we never finish this loop anyway. */
    const uint32_t t0 = millis();
    while (millis() - t0 < 250) IWatchdog.reload();

    /* Still here: the latch had nothing to cut, which is the normal case on a bench
     * supply. Come back up rather than spinning, and re-arm the ignition logic so the
     * board stays usable. */
    digitalWrite(PIN_LATCH_HOLD, HIGH);
    ign_begin(app_ignition_on());
}

/* --- setup ----------------------------------------------------------------- */

void setup(void)
{
    /* 1. HOLD OUR OWN POWER ON. First statement, for the reason in the header. */
    pinMode(PIN_LATCH_HOLD, OUTPUT);
    digitalWrite(PIN_LATCH_HOLD, HIGH);

    /* 2. Shift registers: zeroed, latched, still high-impedance. */
    sr_begin();

    pinMode(PIN_LED1, OUTPUT);
    pinMode(PIN_LED2, OUTPUT);
    pinMode(PIN_IGN_SENSE, INPUT_ANALOG);
    analogReadResolution(12);

    cfg_read_straps();

    store_begin();
    eeprom_ok = store_present();
    cfg_load();                  /* falls back to defaults if the EEPROM is absent */
    proto_sanitise_base();

    ch_begin();

    const bool wdg_reset = IWatchdog.isReset(true);

    /* 3. Adopt the configured resting state, THEN go live.
     *
     * `failsafe_state` means "what should be on when nobody has told us otherwise", and
     * that is as true at power-up as it is after the bus goes quiet. It used to be
     * applied only on a CAN timeout, which meant a board came up with every channel off
     * and did not reach its configured state until can_timeout_ms had elapsed -- so a
     * main relay behind this board closed a second and a half after the key rather than
     * at boot.
     *
     * The boot-order invariant is unchanged and still the important thing: a KNOWN state
     * has to be latched into the 595s before SR_OE_N is allowed to drop. sr_begin()
     * latched zeros; this latches the configured state; only then do the outputs go
     * live. What has gone is the idea that they must go live LAST.
     *
     * Both reset paths do this identically, so the outputs are back within a few
     * milliseconds either way -- on a watchdog reset that is the difference between a
     * glitch and a stall, and on a cold start it is the difference between the engine
     * being ready to crank and waiting on a timeout. */
    read_ignition();
    ign_begin(app_ignition_on());

    ch_apply_failsafe();
    ch_tick(millis());
    app_set_outputs_live(true);

    can_up = can_begin(cfg_effective_bitrate());
    if (can_up) proto_begin();

    if (!wdg_reset) {
        /* Cold boot only: blink the node address on the red LED. N+1 flashes = node N,
         * which confirms the DIP is being read with nothing attached. Worth two seconds
         * once; not worth it on every watchdog reset, and no longer in the way of the
         * outputs coming up. */
        for (uint8_t i = 0; i <= straps.node; i++) {
            digitalWrite(PIN_LED2, HIGH); delay(120);
            digitalWrite(PIN_LED2, LOW);  delay(180);
        }
    }

    /* Last, because the BMI270 config upload is slow and nothing depends on it. */
    if (straps.publish_imu) imu_begin();

    IWatchdog.begin(WDG_US);

    const uint32_t now = millis();
    next_tick = next_bcast = next_imu = next_slow = now;
}

/* --- loop ------------------------------------------------------------------ */

void loop(void)
{
    const uint32_t now = millis();

    /* CAN is polled every time round, not on a deadline. The receive FIFO is three
     * frames deep and commands should not wait for a tick boundary; the transmit
     * queue likewise only moves when something pumps it. */
    if (can_up) {
        can_tx_pump();
        proto_poll(now);
    }

    if ((int32_t)(now - next_tick) >= 0) {
        next_tick += TICK_MS;
        /* If we ever fall far enough behind that the deadline has already passed
         * again, resynchronise instead of trying to catch up with a burst of ticks
         * -- the debounce counters assume a steady interval. */
        if ((int32_t)(now - next_tick) >= 0) next_tick = now + TICK_MS;

        ch_tick(now);
        read_ignition();
        ign_tick(now, app_ignition_on());
        IWatchdog.reload();
    }

    if (can_up && (int32_t)(now - next_bcast) >= 0) {
        next_bcast = now + cfg.broadcast_ms;
        proto_broadcast(now);
    }

    if (can_up && straps.publish_imu && imu_ok() && (int32_t)(now - next_imu) >= 0) {
        next_imu = now + cfg.imu_rate_ms;
        imu_tick();
        imu_broadcast();
    }

    if ((int32_t)(now - next_slow) >= 0) {
        next_slow = now + 100;
        shutdown_check(now);
    }

    leds(now);
}

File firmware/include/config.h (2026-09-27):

/*
 * config.h -- what the board is, and what each channel is for.
 *
 * Two quite different things live here and it is worth keeping them apart:
 *
 *   STRAPS  come from the DIP switch and can only change with the power off. Role,
 *           node address, IMU enable, and the 500k recovery override. These are the
 *           settings you cannot fix over the bus once they are wrong, which is
 *           exactly why they are on a switch and not in EEPROM.
 *
 *   CONFIG  comes from EEPROM and can be changed at runtime over CAN. Bitrate,
 *           message IDs, and the channel mode table -- the in/out decision that this
 *           board deliberately made a software matter rather than a hardware one
 *           (see DESIGN.md, "Channel mode became a software table").
 */
#ifndef RCM_CONFIG_H
#define RCM_CONFIG_H

#include <stdint.h>
#include <stddef.h>
#include <stdbool.h>
#include "board.h"
#include "ignition.h"

/* ---- channel mode table --------------------------------------------------- */
enum ch_mode_t {
    CH_UNUSED = 0,   /* never driven, never diagnosed, not reported as a fault    */
    CH_OUTPUT = 1,   /* drives a relay coil low-side; sense = coil circuit health */
    CH_INPUT  = 2,   /* never driven; sense = a button switching +12V            */
};

/* Channel flags. INVERT applies to the logical value in BOTH directions: an inverted
 * output is energised when commanded off, an inverted input reads pressed when the
 * line is low. NO_DIAG suppresses fault reporting on a channel whose load legitimately
 * looks broken -- an output feeding something other than a relay coil, typically. */
#define CH_F_INVERT   0x01
#define CH_F_NO_DIAG  0x02

#define PEER_NONE     0xFFu

/* HOW a channel behaves when commanded on. Orthogonal to what it is FOR -- an indicator
 * and a rain light are different functions with the same behaviour, and a horn and a
 * washer are different functions that both want a pulse. */
enum ch_behaviour_t {
    OUT_STEADY    = 0,  /* on means on. The default, and what most loads want.       */
    OUT_FLASH     = 1,  /* on means flash, at the shared cfg.flash_period_ms so that
                         * every flashing channel stays in phase -- which is what
                         * makes hazards look right rather than like two indicators
                         * that happen to be on.                                     */
    OUT_PULSE     = 2,  /* on fires a single pulse of `param` ms and then stops, until
                         * released and pressed again. Horn chirp, washer, prime.    */
    OUT_DELAY_OFF = 3,  /* on immediately; off is deferred by `param` ms. Courtesy
                         * lights, fan run-on, anything that should linger.          */
};

/* HOW an INPUT behaves. Shares the `behaviour` byte with ch_behaviour_t, which is
 * outputs-only, so a channel's one behaviour byte means whichever applies to its mode.
 * IN_MOMENTARY is 0, the same as OUT_STEADY, so the default is right for both.
 *
 * These change what the channel REPORTS, not what some output does. That is the useful
 * place for it: a latched keypad button then carries its latched state in the INPUTS
 * frame, so a relay module mirroring that keypad just follows it, the ECU-command
 * binding sees one edge per intent, and a dash shows the real state. Doing it at the
 * destination instead -- which is what peer_toggle_mask does -- only works for the one
 * consumer that implements it. */
enum ch_in_behaviour_t {
    IN_MOMENTARY = 0,  /* reports the switch, as it is. The default.               */
    IN_TOGGLE    = 1,  /* each PRESS flips the reported state and it stays there.
                        * A momentary button driving a latching load.              */
    IN_HOLD_ARM  = 2,  /* reports true only once the switch has been held for
                        * `param` ms, and false the instant it is released. For
                        * things a knock must not arm -- launch control being the
                        * case this exists for.                                    */
};
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

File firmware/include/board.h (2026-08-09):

/*
 * board.h -- RCM pin map and board constants.
 *
 * Every pin here is taken from gen_spec.py's PINMAP -- the same table that produced the
 * schematic and therefore the copper. Do not "tidy" these by hand: a firmware pin map that
 * has drifted from the netlist is a miserable afternoon with a multimeter.
 */
#ifndef RCM_BOARD_H
#define RCM_BOARD_H

/* ---- channels -------------------------------------------------------------
 * 21 universal channels, 7 per TPL7407L. Every channel is an output AND an input
 * simultaneously -- the sense divider never disconnects, so a channel can be read
 * while it is being driven. That is what makes fuse detection free.
 */
#define RCM_CHANNELS          21
#define RCM_TILES              3
#define RCM_CH_PER_TILE        7
#define RCM_AUX_INPUTS         3    /* J_AUX, on the spare bit of each 165 */

/* ---- shift register chains ------------------------------------------------
 * OUT: 3x 74HC595 daisy-chained, 8 bits each. QA..QG drive channels; QH unused.
 * IN : 3x 74HC165 daisy-chained, 8 bits each: 7 channel senses + 1 AUX.
 * Shared clock. PA5/6/7 are SPI1, so both chains can run on hardware SPI.
 */
#define RCM_SR_BYTES           3    /* 24 bits each way */

#define PIN_SR_SCK            PA5   /* SPI1_SCK  -- shared by both chains        */
#define PIN_SR_MISO           PA6   /* SPI1_MISO <- 165 chain data out           */
#define PIN_SR_MOSI           PA7   /* SPI1_MOSI -> 595 chain data in            */
#define PIN_SR_RCLK           PB0   /* 595 storage latch: pulse HIGH to publish  */
#define PIN_SR_PL             PB1   /* 165 parallel load, ACTIVE LOW: pulse to sample */
#define PIN_SR_OE_N           PB2   /* 595 output enable, ACTIVE LOW             */

/* SR_OE_N has a 10k pull-UP (R_OE), so the 595 outputs are high-impedance from
 * the instant power arrives until firmware deliberately drives this low. That is
 * what stops every relay clacking on during boot. Do NOT enable outputs until the
 * shift registers have been loaded with a known state. */

/* ---- config DIP (positions 2-6; position 1 is passive CAN termination) -----
 * Internal pull-ups; the switch shorts to ground. CLOSED reads 0.
 */
#define PIN_CFG_ROLE          PC0   /* closed = keypad, open = relay module      */
#define PIN_CFG_ADDR0         PC1
#define PIN_CFG_ADDR1         PC2   /* ADDR0+1 -> 4 node addresses per role      */
#define PIN_CFG_BAUD          PC3   /* closed = force 500k (recovery), open = use stored */
#define PIN_CFG_IMU_EN        PC4   /* closed = publish IMU; only ONE board per car */

/* ---- ignition latch -------------------------------------------------------
 * The board holds its own power on so it can shut down cleanly after ignition off.
 * LATCH_HOLD must be driven HIGH within the first few ms of main() or the board
 * switches itself off the moment the ignition signal drops.
 */
#define PIN_LATCH_HOLD        PB10
#define PIN_IGN_SENSE         PA0   /* analog: divider off the ignition feed     */

/* ---- CAN ------------------------------------------------------------------ */
#define PIN_CAN_RX            PB8   /* CAN1 */
#define PIN_CAN_TX            PB9

/* ---- IMU (BMI270, I2C1) --------------------------------------------------- */
#define PIN_IMU_SCL           PB6
#define PIN_IMU_SDA           PB7
#define PIN_IMU_INT1          PA1
#define IMU_I2C_ADDR          0x68  /* SDO pulled low by R_ADDR (0R, fitted)     */

/* ---- EEPROM (M95640, SPI2) ------------------------------------------------ */
#define PIN_EEP_CS            PB12
#define PIN_EEP_SCK           PB13
#define PIN_EEP_MISO          PB14
#define PIN_EEP_MOSI          PB15

/* ---- status LEDs ---------------------------------------------------------- */
#define PIN_LED1              PA8   /* green -- dim by design, see DESIGN.md     */
#define PIN_LED2              PB5   /* red                                       */

/* ---- CAN bitrates --------------------------------------------------------- */
#define RCM_BAUD_DEFAULT      500000UL   /* rusEFI default; uaDASH is limited to this */
#define RCM_BAUD_RECOVERY     500000UL   /* what CFG_BAUD closed forces               */

#endif /* RCM_BOARD_H */

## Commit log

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2026-08-05 rcm: schematic generated and verified - ERC 0, netlist round-trip MATCH
    Drops SIM7600 and microSD per the user. That does NOT delete the LDO as I
    previously claimed: the Waveshare module ships set to 5V, and getting 3V3 from
    it needs a per-module pad rework - the same trap already documented on the
    keypad, where forgetting it cooks the MCU. A $0.20 LDO removes a destructive
    manual step, so it stays.
    Verified before drawing rather than assumed:
    - TPL7407L has a 1M internal pull-down per channel, explicitly so tri-stated
    drivers read as OFF. The boot-clack hazard is designed out; no 21 external
    pulldowns needed.
    - The KiCad BMI160 symbol is pin-identical to the BMI270, 14/14 (BST-BMI270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
    [rcm.kicad_sch]
2026-08-05 rcm: drop the ESP32 add-on, and fix three more issues found pre-PCB
    ESP32-C3 co-processor dropped per the user; PA9/PA10 become ordinary spares.
    Second review pass against datasheets found three more problems that ERC and the
    netlist round-trip both passed:
    - No I2C pull-ups anywhere. The BMI270 would never have responded. The datasheet
    line about not needing external pull-ups applies to the auxiliary interface,
    not the primary. 4.7k added; revB already had these as R9/R10.
    - The sense divider failed VIH at rest voltage. 74HC VIH(min) is 0.7*Vcc = 2.31V
    at 3V3, not the ~1.65V typical switching point, so 1M/220k gave 2.16V at 12.0V
    and every channel would have read "circuit broken"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
    [rcm.kicad_sch]
2026-08-05 rcm: board placement complete - 100x100mm, lint clean, DRC 0 errors
    All 154 parts positioned. The three channel tiles are defined once as a
    27-member group and instantiated three times, so 81 of the 154 placements come
    from a single definition - the payoff for choosing the shift-register layout.
    Board is 100x100mm against revB's 216x148, roughly a quarter the area.
    The trap worth recording: JB1 and JB2 are separate footprints for the two
    columns of one buck module, and their courtyards never touch, so nothing checks
    that they line up. They must be 27.80mm apart in X and offset 1.90mm in Y,
    because the IN column's first hole sits 3.60mm from the module edge and the OUT
    column's sits 1.70mm.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
    [rcm.kicad_pcb, rcm.kicad_sch]
2026-08-05 rcm: reshape the board to 140x70 to match the keypad button panel
    The panel is 8 momentary switches in 2 rows of 4 at 35mm each, so the board is
    now 140 x 70mm. That is 98cm2 against the previous 100 x 100mm draft's 100cm2 -
    the same area reshaped rather than a resize, so nothing was traded away for it.
    A 70mm-tall board cannot take the old 46mm channel tiles, so each tile's driver,
    both shift registers and their decoupling now sit in ONE row instead of a
    column: 31mm of tile height, spending the width the wider board has. The north
    half was rebuilt across the full 140mm.
    Two bugs found on the way, both worth remembering:
    - expand_placement pairs members[i] with refs[i]. Reordering the me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
    [rcm.kicad_pcb]
2026-08-05 rcm: reverse the 595 data chain and give the mounting holes washer clearance
    Reviewing the rendered board, the shift-register data line entered at the tile
    FURTHEST from the MCU - a ~74mm haul across the board before the chain doubled
    back east past the MCU. Reversed so it enters at the nearest tile and ripples
    away. Sets the bit order: first byte out lands in U_SO1 (channels 1-7).
    The four mounting holes all sat 3.5-4.0mm from a board edge, which is exactly
    the radius of an M3 washer - it would have overhung. Moved to 5mm+ and lifted
    the two bottom holes clear of the terminal-block row.
    Schematic ERC 0 and round-trip MATCH; placement lint 0/0; board DRC 0 errors.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
    [rcm.kicad_pcb, rcm.kicad_sch]
2026-08-05 rcm: centre the connectors, corner the mounting holes, registers beside resistors
    Three layout changes from reviewing the rendered board:
    - Both terminal groups are now centred on their edge instead of bunched toward
    the ends, which is what freed the corners.
    - The four mounting holes moved to the corners, 5mm clear of the edge.
    - Each tile's driver and both shift registers now sit BESIDE the resistor block
    rather than in a row above it. The registers are what those resistors talk to,
    so they are next to their own signals instead of a tile-width away.
    The members/refs pairing bug bit a second time during this rework - reordering
    the tile offsets without reordering the ref list put U_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
    [rcm.kicad_pcb]
2026-08-05 rcm: registers back north of the resistors, everything spread along the length
    Walks back the beside-the-resistors arrangement. The driver and both shift
    registers are in a row north of the resistor block again, and the channel
    columns now use a 6.0mm pitch - wider than the terminal's 3.5mm poles - so the
    resistor rows and the registers above them spread evenly along the board instead
    of bunching into tight clusters with dead space between them. That extra spacing
    is also routing room. About 8mm of margin is left at each end.
    Terminals stay centred on their edges and the mounting holes stay in the
    corners.
    Placement lint 0/0, board DRC 0 errors.
    Note to self: read the DRC output, not just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
    [rcm.kicad_pcb]
2026-08-05 rcm: move the status LEDs beside PWR_IN, and settle the mounting holes
    LEDs relocated to the north edge next to J_PWR per the user, who notes they will
    likely be covered anyway.
    Mounting holes stay in the corners: the button panel is being 3D-printed after
    this board and made to suit it, so the board drives the panel's fixing pattern
    rather than waiting on an enclosure constraint. That closes the last open
    placement question.
    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
    [rcm.kicad_pcb]
2026-08-05 rcm: board routed - 414/414 nets, 0 unconnected
    Round 1 routed 413 of 414 in 63 seconds and needed NO placement changes for
    congestion, which was the thing we expected to fight. The spread-out layout did
    its job.
    Two real issues came out of it:
    - Starved thermals: a ground pad reaching the pour through one narrow neck. On
    reflow-soldered parts the relief buys nothing, so a solid connection is both
    the fix and the better design. Which pads get starved changes on every
    re-route, so fix_starved_thermals.py reads the DRC report rather than
    hard-coding them - re-run it after every route.
    - USB_CC1 was unroutable: the CC pin sits in a 0.5mm-pitch pad row with no
    escape gap and I had pl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
    [rcm.kicad_pcb]
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2026-08-05 rcm: board fully routed and DRC-clean - 414/414 nets, 0 errors
    Round 5 routes every net with 0 unconnected and, after the thermal pass, 0 DRC
    errors. 2214 segments and vias, ground poured both sides. Only silkscreen
    warnings remain.
    Two real faults fixed, both found by checking rather than assuming:
    - The USB-C opening sat 2.8mm INSIDE the board edge. The +90 rotation pointed it
    east correctly, but a plug would have fouled the PCB before seating. Moved
    flush. The resulting NEAR EDGE lint warning is the correct outcome for an edge
    connector.
    - BOOT0 failed three consecutive runs with a byte-identical stub and identical
    score. I dismissed it as a stochastic router artifact and sugges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
    [rcm.kicad_pcb]
2026-08-05 rcm: shift the MCU into the dead space, and fix the button pull-up for wetting current
    MCU moved right and down into the empty area, away from the tight strip above it.
    The decoupling row and R_BOOT are now positioned relative to the MCU so the BOOT0
    escape lane fixed last round travels with it. Round 6 routes 414/414 with 0
    unconnected and 0 DRC errors, in 2149 segments - fewer than before, so the move
    improved routability slightly.
    Button pull-up 100k -> 10k. At 12V a 100k pull-up passes only ~120uA through a
    closed contact, below the ~1mA most mechanical contacts need to break through
    surface film. Gold contacts are fine at microamps, ordinary automotive buttons
    are not, and it fails in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
    [rcm.kicad_pcb, rcm.kicad_sch]
2026-08-05 rcm: MCU-east cluster spread out, and fix the THT thermal bug properly
    Rehomed the six aux-input dividers from x~99-107 - where they sat on top of the
    MCU - into a single row under J_AUX at x=70, which is the connector they actually
    belong to. That was a routing inefficiency as much as a crowding one. The CAN and
    IMU groups then spread west into the space it freed.
    Round 9: 414/414 nets, 0 unconnected, 0 DRC errors, 2231 segments.
    Fixed fix_starved_thermals.py rather than the board. The DRC report writes
    "PTH pad 5 [GND] of J_SWD" for through-hole but "Pad 12 [GND] of U1" for SMD, and
    the parser only matched the latter - so it reported "nothing to do" while every
    THT violation remained. I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
    [rcm.kicad_pcb]
2026-08-05 rcm: put both crystals beside their own pins - placement complete
    Read the MCU pin positions off the placed board: PC14/PC15 (LSE) and PH0/PH1
    (HSE) are all on the chip's west edge. Y1 was 14mm away and Y2 was on the wrong
    side of the chip entirely at 20mm, with its signals crossing the whole package.
    Both are now 6.8mm from their pins. Nothing ever flagged this - both were legally
    placed and fully routed throughout.
    C_VCAP and C_VDDA moved south of the MCU to free that edge. The actual blocker
    turned out to be J_BOOT, a 3-pin jumper with no placement constraints at all;
    several attempts went into fitting a capacitor around it before moving the jumper
    solved it at once.
    Also settled the qu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
    [rcm.kicad_pcb]
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2026-08-06 rcm: restore the GND pour - round 3 was routed without --zone
    route_board.py's --zone defaults to empty, so omitting it produced a
    fully routed, 0-unconnected, DRC-clean board with no copper pour on
    either layer. Nothing in any report flagged it: an absent zone violates
    no design rule, so DRC, the router summary and the netlist round-trip
    were all clean and all silent. Caught by eye off the 3D view.
    Re-routed with --zone GND:F.Cu --zone GND:B.Cu (2 zones, both filled,
    33 polygons), then fix_starved_thermals.py set J_USB.A12, J_USB.B1 and
    U_MCU.47 solid where thermal spokes came up short.
    Board is otherwise where it was: 414/414 routed, 0 unconnected, 0
    schematic parity, 26 silkscreen warni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
    [rcm-B_Cu.gbr, rcm-B_Mask.gbr, rcm-B_Paste.gbr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]
2026-08-06 rcm: latch part -> BTS7040-1EPZ, C534837 went to zero stock
    JLC's quote priced 38 of 39 BOM lines; C534837 (BTS7040-1EPA) is
    unbuyable. Swapped to C534838, BTS7040-1EPZ: same base part number, so
    the Z is a temperature/variant grade rather than a different die and the
    pinout is near-certain rather than resting on family convention. Same
    PG-TSDSO-14-22 package, and better on both specs that matter - 19mOhm
    against 36, and -40..+175C against +150.
    The RCM:BTS70xx-1E symbol was built as a generic family part, which is
    what made this a value-string change rather than a re-layout.
    Stock is thin at ~10 pieces - enough for this run of 5 with spares. If it
    goes, fall back to C534825 BTS7004-1EPP (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
    [bom_jlc.csv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]
2026-08-06 rcm: channel mode becomes a software table; add config DIP switch
    Abandons the 21-DIP-switch plan and makes the board simpler instead.
    The blocker was only ever the pull-UP: R_PU as 10k to +12V makes a blown
    fuse read 2.531V and a good one 2.551V - both HIGH, 20mV apart, fuse
    sensing dead. A 10k pull-DOWN does not, because the ~85 ohm relay coil
    swamps it. All four states then read correctly with the SAME resistor
    fitted on every channel:
    output, fuse good 2.530V HIGH input, button open 0.000V LOW
    output, fuse blown 0.000V LOW input, button closed 2.551V HIGH
    So nothing is mode-dependent, there is nothing for hardware to select,
    and in/out is purely a firmware table.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
    [bom_jlc.csv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]
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2026-08-07 rcm: apply the GND-to-pour version for review (NOT orderable)
    Applied rcm_noroute to rcm.kicad_pcb so it can be looked at. Good board
    is in git and at rcm.kicad_pcb.bak_gnd_routed; mfg/ still matches the
    GOOD board, not what is on disk.
    good 426/426 routed, 2078 segments, 166 vias, 0 unconnected
    this 293/293 routed, 1605 segments (-23%), 165 vias, 25 unconnected
    Electrical DRC is clean on both. What remains here is 8 GND pads the pour
    cannot reach - five of them MCU grounds - plus pour-island-to-island
    items.
    Fixes to stitch_zone_vias.py, all found by running the FULL DRC on the
    first attempt rather than only checking connectivity:
    - rescue traces were checked against pad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
    [rcm.kicad_pcb, rcm_noroute.kicad_pcb]
2026-08-07 rcm: keep MCU grounds routed, rest to the pour - 8 isolated pads -> 3
    route_board.py gains --no-route-keep: a reference prefix whose pins stay
    in the --no-route net. Keeping U_MCU's 5 ground pins in the netlist while
    handing the other 131 to the pour fixes the failure mode outright.
    good board 2078 segments, 166 vias, 0 unconnected
    GND fully to pour 1605 segments, 165 vias, 8 isolated pads (5 MCU gnd)
    GND except MCU 1574 segments, 208 vias, 3 isolated pads (no MCU gnd)
    The MCU's grounds are boxed in by its own escape routing so the pour was
    never going to reach them, but they are trivial for the router once back
    in the netlist - and it cost nothing in copper (1574 vs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
    [rcm.kicad_pcb, rcm_noroute.kicad_pcb]
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2026-08-07 rcm: examine the 4-layer unconnected items, stitch a floating 43mm2 patch
    They are not isolated pads - every pad is connected. They are pour
    fragments on the outer layers:
    GND_plane 1 island, 0 orphaned <- the layer that matters is perfect
    F.Cu 39 islands, 3 orphaned (8.2, 1.25, 0.89 mm2)
    B.Cu 14 islands, 1 orphaned (1.34 mm2)
    Found and fixed one real problem: a 43mm2 floating patch on B.Cu, which
    was floating because stitch_zone_vias.py only ever examined F.Cu and
    never attempted B.Cu islands at all. Now stitched.
    Island removal enabled on both outer pours so unconnected copper is
    deleted rather than left floating. It did NOT change the DRC count, and I
    have not co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
    [rcm4.kicad_pcb]
2026-08-07 rcm4: silkscreen pass done - converged at 25 cosmetic warnings
    13 text-over-text, 12 text-over-pad, across 23 refs, concentrated in the
    crowded north-east cluster (U_CAN, J_CAN2, U_MCU) and the tile-1 shift
    registers. Same floor the 2-layer board reached.
    Both levers are exhausted: ref text is already at 0.8mm, JLC's minimum
    height, and relocate_refs reports 0 moves because there is nowhere left
    to put anything. The 12 text-over-pad resolve themselves at manufacture
    since fabs clip silk off pads; the 13 text-over-text would need a
    placement change to clear.
    Board is otherwise clean: 0 electrical DRC violations, 0 schematic
    parity, no unconnected pads.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
    [rcm4.kicad_pcb]
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2026-08-07 rcm: C_VCAP -> C377773, the only Basic swap available in the BOM
    Checked all 20 Extended lines in the JLC assembly order against the Basic
    library. Exactly one has a Basic equivalent:
    C_VCAP 2.2uF 0805 C77081 (ext) -> C377773 (BASIC), 1.7M stock
    50V/X5R against 25V/X7R: voltage is irrelevant at ~1.2V on VCAP and there
    is no DC bias derating worth mentioning, but X5R tops out at +85C where
    X7R reaches +125C. Fine for a cabin-mounted board; worth knowing if it
    ever moves somewhere hot.
    Nothing else converts. The remaining 19 Extended lines are specialist ICs
    (MCU, IMU, CAN transceiver, TPL7407L, EEPROM, PROFET, 74HC165),
    connectors (three terminal sizes, USB-C, DIP switch) and a handful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
    [bom_jlc.csv, rcm.kicad_sch]
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2026-08-08 rcm: FIX D1 wired backwards - board would never have powered up
    Diode:SS34 uses KiCad's pin 1 = K, pin 2 = A convention, not the
    pin-1-is-anode you would assume. The netlist had D1.1 (cathode) on
    +12V_FUSED and D1.2 (anode) on +12V_P, putting the reverse-polarity diode
    in backwards. It would have blocked the battery feed outright.
    Found by the user reading the schematic symbol and noticing the cathode
    bar pointed at the fuse.
    Nothing automated caught this and nothing was going to: ERC passes either
    orientation because a diode is a valid two-pin connection both ways, and
    DRC, the netlist round-trip and the BOM are all equally blind. Same class
    as the four faults found in the first schematic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
    [rcm.kicad_sch, rcm4.kicad_pcb]
2026-08-08 rcm: D1 corrected in place on both boards - no re-route needed
    The netlist fix swapped which net each of D1's two pads carries. Because
    D_SMA's pads are symmetric about the footprint origin, rotating the part
    180 degrees lands pad 1 exactly where pad 2 was - so rotating AND
    reassigning the nets together lets the existing traces arrive at the
    right pads with no routing changed at all. That matters on rcm4, where
    the routing has been hand-tidied and is not reproducible from a rebuild.
    Both boards verified electrically rather than just DRC-clean:
    rcm4 pad2 (A) = +12V_FUSED, pad1 (K) = +12V_P
    rcm pad2 (A) = +12V_FUSED, pad1 (K) = +12V_P
    Current flows fuse -> anode -> cathode -> prote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
    [rcm.kicad_pcb, rcm4.kicad_pcb]
2026-08-08 rcm4 READY: 0 violations of any kind, manufacturing set regenerated
    Final state of the 4-layer board after the user's trace tidy-up and the
    D1 correction:
    0 DRC violations - not just electrical, silkscreen too
    0 unconnected, 0 schematic parity
    4 zones, 189 vias, 1765 segments
    mfg4/ regenerated: 16 gerbers, BOM 43 lines all sourced, CPL 152
    placements. Both planes export as a SINGLE filled region, silkscreen has
    no pad flashes or clear-polarity blocks, outline exactly 140.00x70.00mm.
    Re-inserted the stackup, which KiCad had discarded when the board was
    saved from the GUI - almost certainly because my block named the inner
    layers In1.Cu/In2.Cu while the board calls them GND_plane/PWR_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
    [cpl_jlc.csv, rcm-B_Cu.gbr, rcm-B_Mask.gbr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]
2026-08-08 rcm4: record leaded HASL as the finish, not ENIG
    Revising the earlier ENIG recommendation. The quote already includes
    X-Ray Inspection at $8.20, which is there for the BMI270's LGA-14 and
    catches precisely the hidden-joint failure ENIG was insurance against.
    The LGA is also the only part on the board that cares - every other
    fine-pitch package (LQFP-64 at 0.5mm, TSSOP-16, USB-C) has compliant
    leads that absorb pad unevenness. One 14-pad part does not justify ~15%
    of the order, especially with 5 boards built and 2 needed.
    Stackup copper_finish set to HAL SnPb to match the order form's
    HASL(with lead), which is also the flatter of the two HASL options.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
    [rcm4.kicad_pcb]
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2026-08-08 rcm: fold FOURLAYER.md into SPEC.md, start firmware with a generated pin map
    Only one board remains, so the separate 4-layer notes belong in SPEC.md.
    firmware/include/board.h is GENERATED from gen_spec.py's PINMAP - the
    same table that produced the schematic and therefore the copper - rather
    than typed. All 27 defines resolved against the real netlist with no
    placeholders. Regenerate rather than hand-edit if the hardware moves.
    firmware/README.md records the shape of the problem and, more usefully,
    the things already decided in hardware: rusEFI at 500kbps default, channel
    mode as a software table, active-low config bits. Plus the trap worth
    designing around - a channel's mode CANNOT be inf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
    [board.h]
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2026-08-09 firmware: bring-up plan, complete pin map, milestone 1
    Adds the three shift-register control pins missing from board.h - SR_RCLK,
    SR_PL and SR_OE_N - so the map is now complete against PINMAP. Also notes
    that PA5/6/7 are SPI1, so both chains can run on hardware SPI rather than
    bit-banging.
    The plan argues for incremental bring-up but NOT starting with CAN. The
    ordering is forced by hardware: LATCH_HOLD must go high within a few ms of
    main() or the board cuts its own power when ignition drops, so nothing is
    debuggable until that works. Milestones 1 and 2 need no CAN at all and are
    verifiable with a multimeter on a bench supply.
    CAN bitrate: 500k default since uaDASH is limited to it, but st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
    [board.h, main.cpp]
2026-08-10 firmware: the whole tree, plus the generated DBC
    Written and host-tested in an earlier session but never committed. 21
    channels with a software in/out table, coil-circuit diagnosis, configurable
    bitrate with a DIP-switch escape back to 500k, node addressing, CAN-loss
    failsafe and optional keypad-to-relay peer mirroring.
    docs/rcm.dbc is generated by firmware/tools/gen_dbc.py from protocol.h --
    do not hand-edit it.
    Never run on hardware; the boards have not arrived.
    [SPI.h, canbus.cpp]
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2026-08-14 firmware: recover fast from a watchdog reset
    On any reset SR_OE_N is released and R_OE parks the 595s high-impedance, so
    every channel drops until firmware re-enables them. setup() was doing the
    node-address blink (up to 2.4s on node 7) and the BMI270's 8KB config upload
    BEFORE that point -- several seconds of every channel off, which is the
    difference between a glitch and a stall if a channel is holding something
    running.
    Now detects a watchdog reset, and in that case skips the blink, applies
    failsafe_state and enables the outputs within milliseconds. The IMU init
    moves after outputs-live on both paths. Cold boot still blinks the address,
    which is worth two seconds once.
    Prompted by a sec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
    [main.cpp]
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2026-08-15 MIT licence, and correct the overstated engine-load warning
    The README said "don't put engine-critical loads behind it", which is wrong
    for a PDM -- running a main relay is the job. The real constraint is that
    any reset parks all channels high-impedance until firmware re-enables them,
    so the useful question is what 10ms off does to a given load, not whether
    that load is engine-critical. Rewritten as a table:
    fan/pump/lights invisible
    injector supply at worst one missed event -- fine, set failsafe_state
    ECU power itself the ECU reboots, which IS a stall -- don't
    brake lights hardwire, but for simplicity, not for dropout time
    Rather than leave that 10ms as an assertion, the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
    [selftest_main.cpp]
2026-08-15 firmware: failsafe_state is the resting state, applied at boot too
    It was only applied on a CAN timeout, so a board came up with every channel
    off and did not reach its configured state until can_timeout_ms had elapsed.
    A main relay behind this board would have closed ~1.6s after the key (600ms
    boot for node 1, then the 1s timeout) rather than at boot.
    Now both reset paths adopt failsafe_state and enable the outputs
    immediately, ~10ms either way. The node-address blink moves after
    outputs-live on the cold path -- it is an LED, it was never a reason to
    hold 21 channels off.
    The boot-order invariant is unchanged and is still the point: a KNOWN state
    must be latched into the 595s before SR_OE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
    [main.cpp, selftest_main.cpp]
2026-08-15 test: pin down what a board actually does at boot
    Asked whether adopting failsafe_state at boot means everything turns on.
    It does not, and that deserved evidence rather than my word:
    - a default board (failsafe_state = 0) comes up with all 21 channels off
    - a zero bit on an INVERTED channel still means not-energised, so inverted
    channels do not silently energise themselves at boot
    - an input-mode channel is never driven even if failsafe_state asks for it
    102 tests.
    [main.cpp]
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
